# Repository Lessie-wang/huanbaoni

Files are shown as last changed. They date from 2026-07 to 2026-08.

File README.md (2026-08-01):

# 环抱你 · 知愈 Ring

> 一枚会「环抱你」的情绪陪伴戒指 —— 情绪实时感知、压力早期拦截、成长画像与温柔陪伴。
>
> Buildathon 2026 参赛项目。

戒指两端是一双抽象的手，共同托住可拆卸的六瓣「情绪核心」。它读你的心率与 HRV，识别压力的到来，在你还没意识到之前先用一次轻震「拦」住它；一天结束时，把你的情绪画成一幅画，让小知陪你复盘。

- **线上体验（GitHub Pages）**：https://lessie-wang.github.io/huanbaoni/
- **线上体验（Netlify）**：https://huanbaoni.netlify.app/
- 内置 demo 数据，扫码即用，无需连接真实硬件即可跑通全流程。

---

## 这是什么

「环抱你」= **一枚戒指硬件** + **一个 H5 App**。

- **戒指（输入端）**：MAX30102 采心率/HRV、MPU6050 采运动与「敲击」手势、GSR 采皮肤电，ESP32-S3 通过 BLE 上报，收到指令时用振动马达输出私密触觉。
- **H5（输出端）**：Web Bluetooth 直连戒指，实时显示压力状态；压力升高时分三档触觉干预（早期拦截 / 中期安抚 / 高压环抱）；当天情绪汇总成「心灵画像」，AI 管家「小知」陪你复盘、做量表自测和表达训练。

三档干预触觉的设计意图：**在压力形成早期就打断它**，而不是等崩溃后才安慰。

---

## 目录结构

| 目录 | 内容 |
|---|---|
| `webapp/` | 纯前端 H5 App（无框架、无构建，`index.html` 直接打开即跑）。5 个 Tab + 悬浮 AI 管家小知 |
| `firmware/` | ESP32-S3 Arduino 固件。`huanbaoni/` 是主固件，其余为各传感器 bringup 测试 sketch |
| `hardware/` | 演示外壳（OpenSCAD 源 + STL + 渲染图），容纳开发板与传感器托盘 |
| `cad/` | 戒指本体 3D 打印原型（Blender 源 + 多版本 STL + 预览图） |
| `docs/` | 接口契约、硬件规格、科学依据、分工清单 |
| `tools/` | 上线与现场保险工具（二维码生成、本地兜底服务） |
| `.github/workflows/` | GitHub Pages 自动部署 |

---

## H5 App（`webapp/`）

纯 HTML + CSS + vanilla JS，无框架、无构建步骤。底部 **5 个 Tab**（环抱居中凸起）+ 悬浮 AI 管家小知：

| 页面 | 类型 | 文件 | 作用 |
|---|---|---|---|
| 环抱（主页） | Tab | `pages/realtime.js` | 连戒指 → 实时 HR/HRV → 三色压力环；压力升高自动分档震动 |
| 心灵画像 | Tab | `pages/portrait.js` | 汇总当日情绪 → AI 生成一幅画 + 解读，诚实呈现而非美化负面情绪 |
| 心迹 | Tab | `pages/growth.js` | 画像画廊（色调演变）+ 情绪/压力趋势 + 等级/徽章/连续天数 |
| 探索 | Tab | `pages/tests.js` | HSPS-12 / PSS-10 等学术量表自测 + AI 解读 |
| 修习 | Tab | `pages/training.js` | 表达训练 + 感官写作 |
| 小知（AI 管家） | **悬浮窗** | `pages/chat.js` | 语音闭环对话；压力事件后主动发起复盘；**敲两下戒指**即可全局唤起并开录 |

共享层 `webapp/lib/`：`store.js`（localStorage）、`ble.js`（Web Bluetooth）、`mock.js`（假戒指数据）、`ai.js`（AI 调用）、`tts.js`（语音）、`tokens.css`（设计变量）等。

### 本地运行

直接用浏览器打开 `webapp/index.html` 即可（内置 mock 数据）。或起个静态服务：

```bash
cd webapp && python3 -m http.server 8080
# 打开 http://localhost:8080/
```

连接真实戒指需要支持 Web Bluetooth 的浏览器（Chrome / Edge），并通过 HTTPS 或 localhost 访问。

---

## 固件（`firmware/`）

- `huanbaoni/huanbaoni.ino` —— 主固件：MAX30102 算 HR/HRV、MPU6050 出运动量与双击手势、GSR 读皮肤电，全部通过 BLE Notify 上报；接收 `VIBRATE:*` 指令播放分档振动。
- 其余为分模块 bringup 测试：`i2c_scan/`（扫地址）、`hrtest/`、`gy521test/`、`gsrtest/`、`motortest/`、`mictest/`、`firstlight/`、`bringup_test/`。

BLE UUID、数据格式、下行指令等**接口契约见 [`docs/接口契约.md`](docs/接口契约.md)**（固件与 H5 必须字符串完全一致）。接线针脚与模块尺寸见 [`docs/硬件规格与外壳.md`](docs/硬件规格与外壳.md)。

---

## 部署与上线

**GitHub Pages**：push 到 `main` 后，`.github/workflows/pages.yml` 自动把 `webapp/` 发布为站点根。首次需在仓库 **Settings → Pages → Source = GitHub Actions** 开启一次。

**二维码与现场保险**（网络抽风时用本地热点兜底）见 [`tools/README.md`](tools/README.md)。

---

## 科学依据

压力检测的信号组合（心率 + HRV + 皮肤电 + 加速度）与学术界公认范式一致（WESAD 数据集），触觉干预亦有文献支撑。完整引用见 [`docs/科学依据.md`](docs/科学依据.md)。

---

## 技术栈

纯前端 H5（HTML/CSS/vanilla JS，零依赖零构建）· ESP32-S3 + Arduino · Web Bluetooth · OpenSCAD / Blender 建模。

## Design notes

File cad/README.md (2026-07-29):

# FeelingMosaic「环抱你」3D 打印原型 V1

## 设计结论

- 戒指定位为外观展示原型，不强行容纳 ESP32、MAX30102 开发模块和驱动板。
- 功能演示采用分布式原型：MAX30102 作为外置指夹采集，戒指或手部插件负责震动，ESP32 与驱动板放入底座。
- 戒指是开放式 C 环；两端为抽象双手，共同托住可拆卸六瓣情绪核心。
- 戒圈外有一条绕截面翻转一周的脊线，形成莫比乌斯视觉意象，同时不侵占主要佩戴空间。
- `FeelingMosaic` 字样在 Blender 精修阶段沿戒圈外侧雕刻；底座正面使用更大的品牌字样，保证 FDM 可读性。

## 现场设备约束

Buildathon OnePage 第六章列出的现场打印机型号为 Bambu Lab A1、P2S、X2D、H2D，提供 PLA：红、橙、黄、绿、蓝、黑、灰、白。文档没有列出透明耗材，并提醒硬件资源数量有限、对稳定性有要求时应自备材料。

因此：

- 默认使用白色 PLA 打印主体，灰色或黑色打印结构件。
- 莫兰迪粉棕、香槟金细节通过自带耗材、丙烯笔或喷漆实现。
- “透明底座”不是全透明 PLA，而是开放框架加 0.5-1 mm PET/亚克力透明片。
- 比赛前优先打印戒指和底座；现场打印只作为迭代或备用。

## 戒指参数

| 版本 | 内径 | 用途 |
|---|---:|---|
| S | 18.5 mm | 食指偏细 |
| M | 19.5 mm | 默认版本，优先打印 |
| L | 20.5 mm | 食指偏粗或需要宽松佩戴 |

- 戒圈总宽约 6 mm，最小主体厚度约 3.4 mm。
- 开口角约 60°；PLA 不应反复掰折，建议通过三种尺寸选配，而不是依赖弹性调节。
- 六瓣核心单独打印，可使用两枚 3×2 mm 磁铁或少量可移胶固定。
- 抽象手指直径约 1.1 mm，已按 0.4 mm 喷嘴的可打印下限加粗。
- 可选震动插件预留常见 10 mm 纽扣马达空间；驱动板仍放在底座。

## 底座架构

### 共用电子托盘

- 外形：140×95×12 mm。
- 内部用于放置 ESP32-S3、400 孔面包板、马达驱动板及杜邦线。
- 两条内部导轨用于扎带、双面胶或魔术贴固定。

### 封闭展示版

- 使用 `opaque_emotion_island_lid` 覆盖电子托盘。
- 顶部六瓣浮雕和戒指展示架构成“情绪岛屿”。
- 后侧预留 USB 走线区域；最终精修时再按实物线头开孔。

### 开放透明版

- 使用 `open_clear_panel_frame` 安装在电子托盘上。
- 四周框架之间安装 PET、亚克力或透明包装片，展示内部原型结构。
- 不使用现场未列明的透明 PLA，避免成品浑浊且打印失败。

## 手上震动演示

优先方案：

1. 购买 10 mm 左右、已带引线的纽扣震动马达。
2. 将马达放入 `optional_10mm_coin_motor_insert`。
3. 插件用医用双面胶、透明胶贴在食指侧面或戒指下方。
4. 细线沿手背进入袖口，再连接底座中的驱动板。

无小马达时：将现有带驱动板的震动模块固定在手腕内侧，用腕带遮住，仍能保证震动真实发生在手上。

## 推荐切片参数

- 材料：PLA。
- 喷嘴：按现场机器默认设置；模型按常见 0.4 mm 喷嘴设计。
- 层高：戒指 0.16-0.20 mm；底座 0.24-0.28 mm。
- 墙数：戒指 3-4；底座 2-3。
- 填充：戒指 25-35%；底座 10-15%。
- 支撑：戒指建议树状支撑，仅从热床生成；底座主体尽量不加支撑。
- 首次打印顺序：M 戒指 → 六瓣核心 → 震动插件 → 电子托盘 → 选一个底座上盖。

## 文件

- `cad/output/feelingmosaic_ring_18.5mm.stl`
- `cad/output/feelingmosaic_ring_19.5mm.stl`
- `cad/output/feelingmosaic_ring_20.5mm.stl`
- `cad/output/six_petal_emotion_core.stl`
- `cad/output/electronics_tray_140x95.stl`
- `cad/output/opaque_emotion_island_lid.stl`
- `cad/output/open_clear_panel_frame.stl`
- `cad/output/optional_10mm_coin_motor_insert.stl`

每个 STL 同时提供 OBJ，方便导入 Blender 后做布尔合并、雕字、材质渲染和局部造型调整。

## Blender 精修清单

1. 对戒指主体执行 Voxel Remesh 或 Boolean Union，消除重叠壳体。
2. 沿戒圈外侧雕刻 `FeelingMosaic`，字高不小于 2.5 mm、笔画不小于 0.8 mm、深度 0.5-0.7 mm。
3. 在六瓣核心和双手托座增加 3.2×2.2 mm 磁铁孔。
4. 根据实物 USB 插头、开关和线材尺寸修改底座开孔。
5. 使用 Bambu Studio 的模型修复功能检查非流形边并预览逐层切片。

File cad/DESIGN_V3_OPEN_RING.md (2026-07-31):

# FeelingMosaic「环抱你」开口戒指 V3

## 当前推荐方案

V3 保留 V2 的高级几何与莫比乌斯语言，但完全移除中央宝石：

- 戒指是清晰的开放式 C 环。
- 八面切角截面沿戒圈扭转 180°。
- 两端抽象为相向伸出的几何双手。
- 中央最窄开口约 5 mm，没有宝石、横梁或隐藏连接件。
- 三根渐细指片与下方拇指共同框出负空间，表达“想要拥抱但不过度侵入”。

## 推荐外观

- 首选：枪灰或钛灰哑光主体。
- 备选：哑光银主体，切面边缘轻微抛光。
- 不建议粉色、圆润高光或彩色花朵装饰。
- `FeelingMosaic` 后续刻在戒圈较宽的外侧切面，或只刻在戒指内壁。

## 输出文件

路径：`cad/output/open_v3/`

- `feelingmosaic_open_embrace_ring_18.5mm.stl`
- `feelingmosaic_open_embrace_ring_19.5mm.stl`（默认）
- `feelingmosaic_open_embrace_ring_20.5mm.stl`

每个 STL 同时提供 OBJ。

## 尺寸与打印

- 默认内径：19.5 mm。
- 默认外形约：32.4×33.7×6.0 mm。
- PLA 层高：0.12-0.16 mm。
- 墙数：4；填充：30-40%。
- 建议以开口向上、整体倾斜 30-45° 的方式打印，并使用树状支撑。
- 当前文件由多个封闭实体组成；导入 Bambu Studio 后使用“修复模型/合并重叠体”，或在 Blender 中执行 Voxel Remesh 后再切片。

## 预览

- `cad/previews/open_ring_v3_top.png`
- `cad/previews/open_ring_v3_isometric.png`
- `cad/previews/open_ring_v3_front.png`

底座设计暂缓，后续围绕最终戒指比例重新设计。

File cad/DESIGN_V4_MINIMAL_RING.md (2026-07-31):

# FeelingMosaic 极简开口戒指 V4

## 最终方向

- 删除双手、宝石、镶爪及所有向上翘起的装饰。
- 保留一个干净的开放式圆形 C 环。
- 戒圈采用八面切角截面，视觉高级但不尖锐。
- 两端在约 7 个截面内逐渐收窄至 72%，形成低轮廓钝头。
- 戒圈保留轻微的莫比乌斯半圈扭转，但没有任何结构高于主体轮廓。

## 默认尺寸

- 内径：19.5 mm。
- 外形约：31.4×29.2×5.5 mm。
- 开口角：38°。
- 适合先用灰色或黑色 PLA 打样。

如果实戴偏紧或偏松，同时提供 18.5 mm 和 20.5 mm 两个版本。PLA 不建议通过反复掰动调整尺寸。

## 输出文件

路径：`cad/output/minimal_v4/`

- `feelingmosaic_minimal_open_ring_18.5mm.stl`
- `feelingmosaic_minimal_open_ring_19.5mm.stl`（默认）
- `feelingmosaic_minimal_open_ring_20.5mm.stl`

每个 STL 同时提供 OBJ。

## 打印建议

- 层高：0.12-0.16 mm。
- 墙数：4。
- 填充：30-40%。
- 开口向上，戒圈倾斜 30-45°，使用树状支撑。
- 打印后用 600-1000 目砂纸轻磨端部和外侧切面。
- 表面可喷钛灰、枪灰或哑光银，再覆盖哑光清漆。

## 预览

- `cad/previews/minimal_ring_v4_top.png`
- `cad/previews/minimal_ring_v4_isometric.png`
- `cad/previews/minimal_ring_v4_front.png`

底座暂不继续设计，优先确认戒指实戴比例。

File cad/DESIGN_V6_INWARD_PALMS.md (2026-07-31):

# FeelingMosaic 内向掌心开口戒指 V6

## 当前造型

- 保留开放式圆形戒圈和低调的莫比乌斯扭转。
- 两只手与戒圈端部保持同一高度，不向上翘起。
- 掌片整体向戒指内圆收拢，掌心朝向圆心。
- 每只手的三根几何手指从掌片内缘伸入圆内，形成托住、包覆圆心的拥抱姿态。
- 两手不接触，中央仍保留明确开口。

## 安全与佩戴

- 手部最大半高约 1.7 mm，低于戒圈约 2.75 mm 的最大半高。
- 两手最小打印间隙约 3.1 mm，避免 FDM 拉丝后粘连成一体。
- 手指端部为平直钝面，没有朝上尖角。
- 默认版本整体约 31.3×29.3×5.5 mm。
- 模型为概念展示戒指，正式佩戴前仍建议打磨所有切面和端部。

## 输出文件

路径：`cad/output/inward_palms_v6/`

- `feelingmosaic_inward_palms_ring_18.5mm.stl`
- `feelingmosaic_inward_palms_ring_19.5mm.stl`（默认）
- `feelingmosaic_inward_palms_ring_20.5mm.stl`

每个 STL 同时提供 OBJ。

## 预览

- `cad/previews/inward_palms_ring_v6_top.png`
- `cad/previews/inward_palms_ring_v6_isometric.png`
- `cad/previews/inward_palms_ring_v6_front.png`

V6 取代 V5，修正了掌心向外的问题。

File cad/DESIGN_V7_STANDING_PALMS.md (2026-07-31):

# FeelingMosaic 立掌环抱开口戒指 V7

## 这版修正

- V6 的手虽然伸向内圆，但掌片仍然平躺在戒指平面中。
- V7 以左右戒圈端点的局部切线为旋转轴，将整只手旋转 90°。
- 掌心、三根几何手指和拇指作为完整整体一起立起，没有重新拼成独立装饰片。
- 两只手原本朝上的掌面旋转后都朝向戒指内圆，形成相对收拢的环抱姿态。

## 几何与佩戴

- 默认内径为 19.5 mm，另提供 18.5 mm 和 20.5 mm。
- 默认模型外形约为 31.3 × 31.0 × 6.0 mm。
- 默认模型两手最小顶点间隙约 2.87 mm，适合保留清晰开口。
- 所有尺寸版本的导出网格均无退化三角形、边界边或非流形边。
- 手掌立起后会比平掌版本更容易接触相邻手指，试戴前需要打磨掌缘和指尖。

## 输出文件

路径：`cad/output/standing_palms_v7/`

- `feelingmosaic_standing_palms_ring_18.5mm.stl`
- `feelingmosaic_standing_palms_ring_19.5mm.stl`（默认）
- `feelingmosaic_standing_palms_ring_20.5mm.stl`

每个 STL 同时提供 OBJ。

## 预览

- `cad/previews/standing_palms_ring_v7_gap.png`：从内圆看两只相对掌心。
- `cad/previews/standing_palms_ring_v7_isometric.png`：整体立体效果。
- `cad/previews/standing_palms_ring_v7_top.png`：确认掌片已不再平躺。
- `cad/previews/standing_palms_ring_v7_front.png`：确认手部高度与戒圈关系。

## 打印建议

- 现场展示优先使用 PLA 或 PLA Silk，层高 0.12–0.16 mm，4 道墙。
- 建议让戒圈侧面贴平台或倾斜 30–45°，避免立掌悬空面直接横向打印。
- 开启树状支撑，仅从热床生成，并重点检查掌心背面和指尖下方。
- 切片时合并重叠体；若切片器未自动合并，先在 Blender 中做体素重构或布尔并集。

V7 取代 V6 作为当前立掌方向版本。

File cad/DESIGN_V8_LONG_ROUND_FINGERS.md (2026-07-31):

# FeelingMosaic 加长圆指立掌戒指 V8

- 两只手保持 V7 的立掌、掌心相对姿态。
- 三根手指沿拥抱方向加长，并改为圆柱中段与半球圆头。
- 手指打印直径约 1.28–1.44 mm，适合 0.4 mm 喷嘴的现场 FDM 展示打印。
- 默认 19.5 mm 内径版本两手最小间隙约 1.63 mm。
- 默认外形约 31.3 × 31.0 × 6.8 mm。
- 三种尺寸网格校验均无退化三角形、边界边或非流形边。

默认文件：`cad/output/long_round_fingers_v8/feelingmosaic_long_round_fingers_ring_19.5mm.stl`

快速打印建议：0.4 mm 喷嘴、0.12–0.16 mm 层高、4 道墙、20–35% 填充、树状支撑仅接触热床。建议将戒指侧放或倾斜 35–45°，不要让两只立掌完全悬空横打。

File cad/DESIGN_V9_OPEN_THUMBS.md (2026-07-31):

# FeelingMosaic 张开拇指立掌戒指 V9

- 保留 V8 的立掌、加长圆指和掌心相对姿态。
- 两侧拇指从手指排中分离，向掌心内下方张开约 18°。
- 拇指比其他手指更短、更粗，根部嵌入掌心，末端为圆头。
- 默认内径 19.5 mm，外形约 31.3 × 31.1 × 7.6 mm。
- 默认两手最小间隙约 1.63 mm。
- 网格校验结果为 0 个退化三角形、0 条边界边、0 条非流形边。

立即打印文件：`cad/output/open_thumbs_v9/feelingmosaic_open_thumbs_ring_19.5mm.stl`

建议使用 0.4 mm 喷嘴、0.12–0.16 mm 层高、4 道墙、25–35% 填充。戒指侧放或倾斜 35–45°，树状支撑仅接触热床，重点支撑掌心和张开的拇指下方。

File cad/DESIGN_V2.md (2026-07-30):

# FeelingMosaic「环抱你」高级几何版 V2

## 方向调整

V1 的圆管、花瓣和圆润手掌偏可爱，不再作为主方案。V2 改为珠宝、建筑与工业设计语言：

- 戒圈使用八面切角截面，而不是圆管。
- 截面沿 C 环完成 180° 扭转，莫比乌斯变化直接体现在实体轮廓中。
- 两端的“手”不再写实或圆润，而是抽象成对称的几何掌片、三根镶爪和一根拇指支撑。
- 中央核心改为独立的八面切割宝石，可后续增加 3×2 mm 磁铁孔。
- 底座改为倒角矩形、折面平台和斜撑结构，去除花瓣和水波纹。

## 推荐视觉

- 戒圈：枪灰、钛灰或哑光黑。
- 几何手部：同色金属，或局部香槟银。
- 核心：烟绿色、深海蓝或透明树脂件。
- 封闭底座：浅灰石材感上盖 + 枪灰展架。
- 开放底座：黑色框架 + 0.5-1 mm 透明 PET/亚克力片。

比赛现场只有基础色 PLA 时，优先选择灰色或黑色。打印后使用 600-1000 目砂纸打磨，再喷金属灰底漆和哑光清漆，会比直接使用亮色 PLA 更高级。

## 戒指尺寸

| 文件 | 内径 | 建议 |
|---|---:|---|
| `feelingmosaic_luxury_ring_18.5mm.stl` | 18.5 mm | 食指偏细 |
| `feelingmosaic_luxury_ring_19.5mm.stl` | 19.5 mm | 默认优先打印 |
| `feelingmosaic_luxury_ring_20.5mm.stl` | 20.5 mm | 宽松或食指偏粗 |

默认 19.5 mm 版外形约 32.4×33.7×6.0 mm。主体最薄截面仍超过常见 0.4 mm 喷嘴的安全打印下限。

## 品牌文字

戒指本体较小，FDM 直接打印完整 `FeelingMosaic` 容易糊字。V2 建议：

1. 戒圈只做激光雕刻、转印或油漆笔书写的 `FeelingMosaic`；
2. 底座正面的 64×11 mm 品牌条打印完整名称；
3. 若后续使用树脂打印，再把 0.4-0.6 mm 深的完整文字刻入戒圈外侧。

## V2 输出文件

路径：`cad/output/luxury_v2/`

- 三种尺寸高级戒指 STL/OBJ。
- `faceted_mosaic_core.stl`：切割宝石核心。
- `luxury_electronics_tray_150x100.stl`：150×100 mm 电子托盘。
- `luxury_closed_architectural_lid.stl`：封闭建筑感上盖。
- `luxury_open_display_frame.stl`：透明片开放框架。

## 打印建议

- 戒指层高：0.12-0.16 mm。
- 戒指墙数：4；填充 30-40%。
- 戒指摆放：开口向上倾斜约 30-45°，使用树状支撑。
- 宝石核心：平放打印；如果使用磁铁，先打印无孔版确认比例，再按磁铁实测尺寸开孔。
- 底座层高：0.20-0.28 mm；墙数 3；填充 10-15%。
- 开放框架建议黑色 PLA；封闭上盖建议灰色 PLA。

## 预览

- `cad/previews/luxury_ring_v2_isometric.png`
- `cad/previews/luxury_ring_v2_top.png`
- `cad/previews/luxury_base_v2_variants.png`

V2 为当前推荐方向，V1 文件仅保留作方案对比。

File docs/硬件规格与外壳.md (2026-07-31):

# 硬件规格与外壳设计 · 「环抱你·小白」

> 本文件汇总所有硬件模块的实测尺寸、接线针脚与外壳设计方案，供 3D 建模和演示搭建复用。
> 图片存于 `docs/hardware/`（已从临时来源复制进仓库，长期有效）。

---

## 一、模块尺寸总表

| 模块 | 作用 | 尺寸 (mm) | 关键点 | 图 |
|---|---|---|---|---|
| ESP32-S3 主控 | 主控 + BLE | PCB 27.9 × 57.2（含 USB 端到端 63.3） | 双 Type-C 在短边并排；排针行间距 25.4；PCB 厚 1.6 | `hardware/esp32-s3.png` |
| MAX30102 | 心率 / HRV / 血氧 | 15.5 × 20 | 感光窗在板中央，需**朝上贴指腹** | `hardware/max30102.jpg` |
| MPU6050 (GY-521) | 六轴运动 + 敲击手势 | 21 × 16 | 8 针：INT/ADO/XCL/XDA/SDA/SCL/GND/VCC | `hardware/mpu6050.jpg` |
| 振动马达模块 | 私密震动输出 | 板 21 × 30；马达 ⌀10 × 厚 2.7（扁平） | 固定孔 ⌀3，孔距 15；5V，MOS 高电平触发；针 IN/VCC/GND | `hardware/motor.jpg` |
| INMP441 麦克风 | 环境音（P1，可选） | 14 × 14 圆板 | 装盒内，I2S | `hardware/inmp441.jpg` |
| GSR 皮肤电 | 情绪唤醒 | 34 × 25，重 4g | **3.5mm 音频座**接指套电极；针 GND/VCC/OUT；3.3–5V | `hardware/gsr.jpg` |
| 半长面包板 | 走线底板 | 56 × 83 × 8.5（由原方案减半） | ABS，0.8mm 跳线 | `hardware/breadboard.jpg` |

**待补测量**（无卡尺可先跳过，试打后微调）：
- ESP32 两个 Type-C 口的**中心间距**、**口下沿距 PCB 底面高度**、口是否凸出板边。
- 各模块焊排针后的**总高**。

---

## 二、接线针脚对照（与 `docs/接口契约.md` / 固件一致）

| 模块针脚 | 接到 ESP32 | 说明 |
|---|---|---|
| MAX30102 SDA / SCL | GPIO8 / GPIO9 | I2C（与 MPU 共用总线，地址 0x57） |
| MAX30102 VIN / GND | 3V3 / GND | |
| MPU6050 SDA / SCL | GPIO8 / GPIO9 | I2C 并联（地址 0x68，AD0→GND） |
| MPU6050 VCC / GND | 3V3 / GND | |
| 振动马达 IN | GPIO5 | PWM，高电平触发 |
| 振动马达 VCC / GND | 3V3 / GND | |
| GSR OUT | GPIO10 | ADC1（必须 GPIO1~10，避开 ADC2 与 BLE 冲突） |
| GSR VCC / GND | 3V3 / GND | |
| GSR 3.5mm 座 | — | 外接两指电极 |
| INMP441 (I2S) | 参见 mictest 接线 | P1 可选，未接进主固件 |

> ⚠️ 3V3 针脚只有两个 → 面包板电源轨分电。**注意：面包板电源轨中间有断缝，左右两半不通，务必跨接或同侧取电**（曾因此调试数小时）。

---

## 三、「环抱你·小白」立体角色外壳

> 外观不是盒子贴角色，而是一个无脸、无耳的抽象拥抱精灵。矩形电子仓只存在于梨形肚子的内部，任何外部视角都保持连续椭圆曲面。

### 空间与轮廓

- **内部净空**：`62 × 32 × 90mm`，半长面包板 `56 × 83 × 8.5mm` 竖装；ESP32、GSR、马达驱动和走线仍使用原规划深度。
- **主体外形**：约 `110 × 82 × 153mm`（不含向前伸出的抱臂）；由一条稠密的梨形曲线旋转成型，再做前后椭圆压缩，整个肚子是一张连续曲面。
- **整体握持深度**：含抱臂约 `117mm`；双臂前移后，肚子与前臂之间留 `hand_clearance=22mm` 净空。
- **识别方式**：无五官、无耳朵、无戒指或 Ring 字样；只用小头、梨形身体和“抱住人的手”的动作表达「环抱你」。
- **壳体结构**：身体沿左右侧轮廓分为前/后两半，接缝位于 `y=0`；后壳四枚 `⌀5.8mm` 球头扣入前壳带释压槽的卡座，保留约 0.35mm 配合量，可反复开壳调试。

### 握持交互

1. 用户从正面把手掌插入小白肚子与双臂之间。
2. 掌心自然压住正面的 MAX30102 H 型托盘，手指可以环握梨形肚子。
3. 小白的粗短 C 形手臂包在手掌两侧，掌球和大拇指位于内上侧，不压传感器。
4. `hand_clearance` 是单一可调参数；试握后只需改这个值即可前后移动整段抱臂。

### 功能接口布局（尺寸不变）

- **正面**：仅 MAX30102 H 型托盘，板槽 `15.5 × 20mm`、总开口宽 `17mm`、中桥 `4.5mm`、双侧贯穿槽长 `20mm`。
- **背面上方**：MPU6050 L 型托盘，板位 `16 × 21mm`、排针槽 `5 × 22mm`，方便直接敲击。
- **背面中部**：GSR 和马达两个 `⌀9mm` 圆孔，中心距 `14mm`。
- **真正底部（两脚之间）**：双 Type-C 独立孔，每个 `11 × 6mm`，横向中心距仍为待实测的 `13mm`。ESP32 在下腹中央竖装：PCB 宽 `27.9mm` 由左右导轨夹持，`57.2mm` 长轴沿身体高度，Type-C 短边垂直朝下。拿起小白即可插线，站立时两脚把接口架空；这避免了背向安装所需的 `63.3mm` 前后空间，也不占面包板后层。

### 工程校验

- `wall_check` 会将主电子仓和 ESP32 下腹板槽向外扩 2.4mm 后与梨形内壳求差（忽略底部 Type-C 开口所在的 `z<5mm`）；当前结果为空，表示所需净空完整装得下。
- 手臂通过隐藏的 `⌀7.4mm` 肩榫插入前壳，孔侧留 0.35mm 配合量，实际握持受力不只依赖胶面；手臂本体采用连续曲线扫掠网格，圆肩—圆肘—前臂之间没有分段锥面。
- 前壳、后壳、左右手臂均已通过 OpenSCAD CGAL 封闭实体检查。
- ⚠️ 试打前仍必须实测 `usb_center_spacing`，这是目前唯一沿用估值的关键接口参数。

### 文件与导出

- 参数化源文件：`hardware/enclosure.scad`
- 单件：`hardware/body_front.stl`、`hardware/body_back.stl`、`hardware/arms.stl`
- 一次排版：`hardware/print_all.stl`（前后壳接缝面朝下，双臂侧躺；适配 256 × 256mm 打印板）
- 预览：`hardware/assembled.png`、`hardware/assembled_front.png`、`hardware/assembled_back.png`、`hardware/assembled_side.png`
- `show`：`assembled` / `body_front` / `body_back` / `arm` / `arm_l` / `arms` / `grip_check` / `cavity_check` / `wall_check` / `print`

```bash
openscad -o hardware/body_front.stl -D 'show="body_front"' hardware/enclosure.scad
openscad -o hardware/body_back.stl  -D 'show="body_back"'  hardware/enclosure.scad
openscad -o hardware/arms.stl       -D 'show="arms"'       hardware/enclosure.scad
openscad -o hardware/print_all.stl  -D 'show="print"'      hardware/enclosure.scad
```

建议全体使用暖白 PLA；手臂与身体同色，靠真实体块和阴影表达拥抱，不再使用肤色贴件或表面角色图案。

---

## 四、打印时间优化

- 主体由“实心体块再挖矩形槽”改为约 `2.8–4.0mm` 的连续有机薄壳，外观、内部净空和所有接口坐标不变。
- 面包板和 ESP32 不再依赖大块实心托盘，改用两侧导轨、底托/顶挡和与壳体相连的短加强筋。
- 四枚球头卡扣各用一条窄径向筋连回后壳，位于 `62mm` 电子仓宽度之外，不会挤占元器件空间。
- 手臂仍为同一条连续扫掠曲面，只将网格采样从 `40×40` 降为 `28×28`；圆肩、圆肘和掌球的实际尺寸不变。
- STL 体积校验：前后壳合计由约 `528.7cm³` 降为 `187.6cm³`，减少约 **64.5%**。这是用料/打印时间的几何代理值；最终分钟数仍取决于层高、壁数、填充和支撑策略。

推荐切片起点：`0.24mm` 层高、3 道壁、15% 局部填充；前后壳用平整接缝面朝下，手臂侧躺并仅对悬空局部生成支撑。

---

## 五、模块图片索引

- ESP32-S3 主控（含 mil 尺寸）：`hardware/esp32-s3.png`
- MAX30102 心率血氧：`hardware/max30102.jpg`
- MPU6050 GY-521：`hardware/mpu6050.jpg`
- 振动马达模块：`hardware/motor.jpg`
- INMP441 麦克风：`hardware/inmp441.jpg`
- GSR 皮肤电传感器：`hardware/gsr.jpg`
- 面包板：`hardware/breadboard.jpg`

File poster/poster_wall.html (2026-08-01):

知愈 · Ring 真系列

软 硬 兼 得 BUILDATHON 2026 · NEXT WORLD

「环抱你」

会环抱你的情绪伙伴

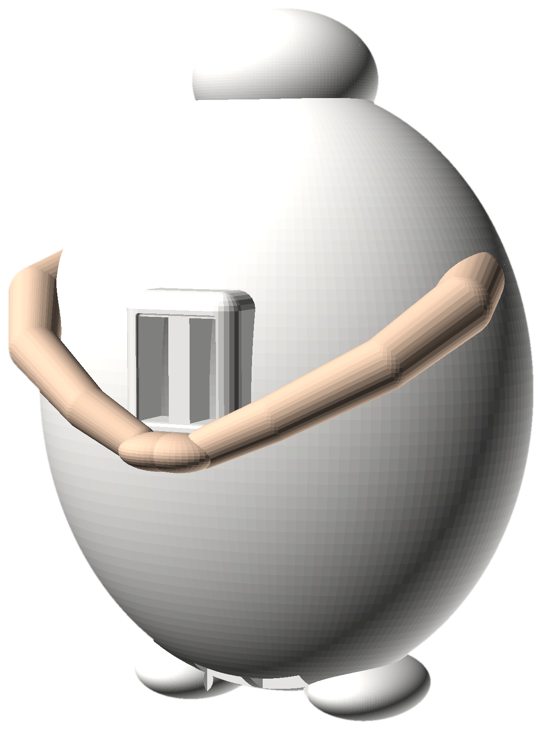
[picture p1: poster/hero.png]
环抱你


舒展 波动 紧绷

先环抱自己，再环抱你

白色身体 · 鎏光香槟手臂 · 未来集成于指间

你的身体，比你先知道 ——
它，是身体递给意识的那张纸条。

HARDWARE无感采集层· 戴上即感知，记录成本归零

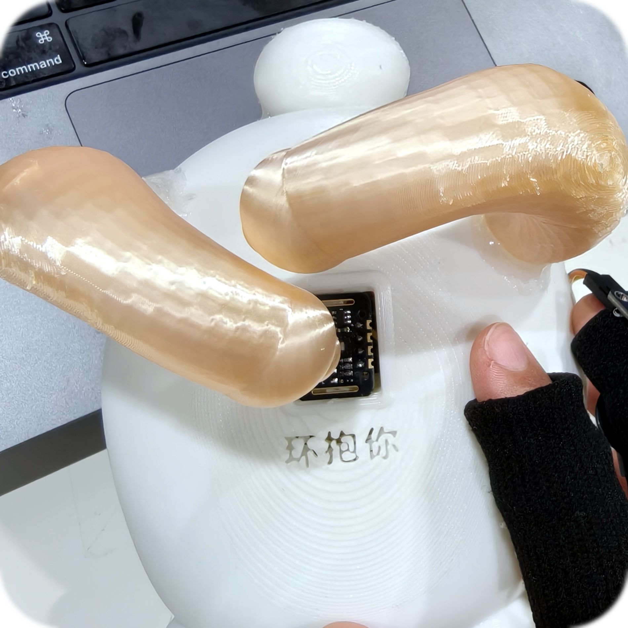
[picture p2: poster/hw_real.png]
真机
真机实拍 

小白 · ESP32-S3 + 五传感器 · 现场手作

PRE-CONSCIOUS

身体比你先知道

HRV 在你意识到之前先塌陷
抓住那 10–20 秒预警窗

心率 · HRVMAX30102

光学采集，衡量绷紧还是放松

皮肤电 GSR唤醒

情绪唤醒，先于意识升高

运动 + 敲击MPU6050

区分紧张与手部活动 · 敲两下唤醒

私密震动三档

只有你知道的那一下：拦截·锚定·撤退

SOFTWARE情绪炼金层· 把冷数据，炼成一个心灵世界

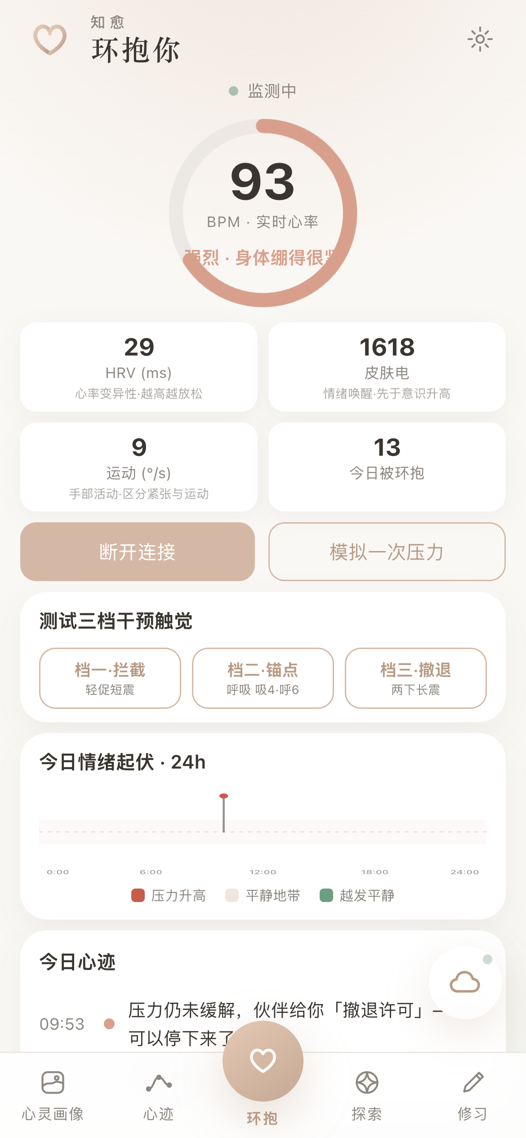
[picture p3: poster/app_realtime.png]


实时环抱三色压力环 · 私密震动

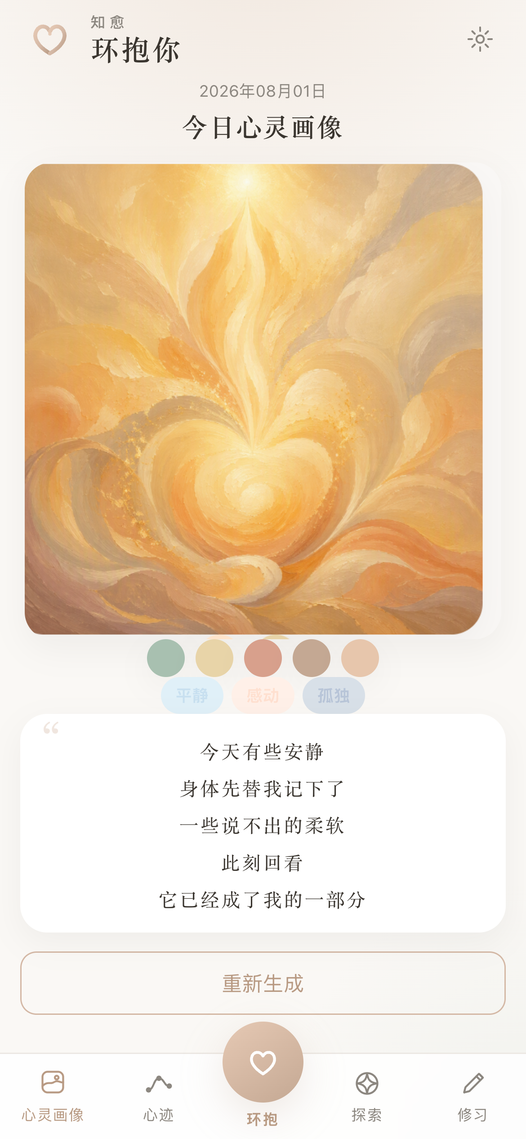
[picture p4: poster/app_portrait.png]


今日心灵画像AI 把情绪炼成画

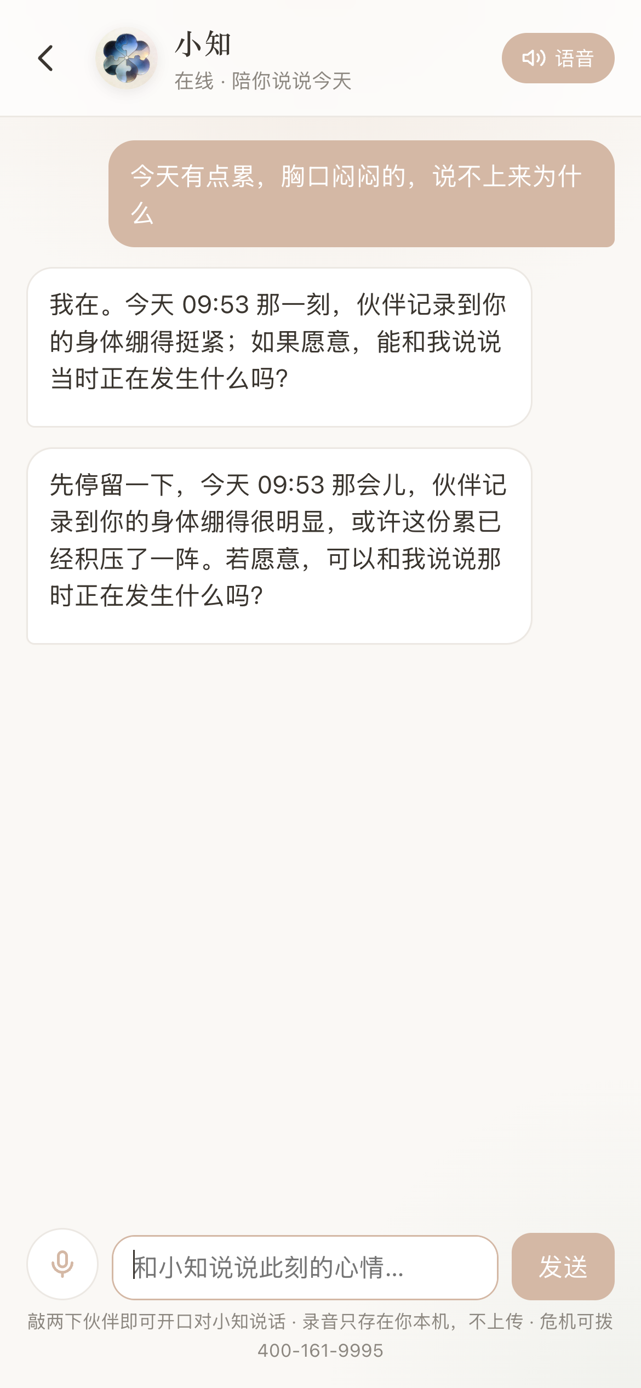
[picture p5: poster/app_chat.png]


小知复盘敲两下伙伴，陪你说说

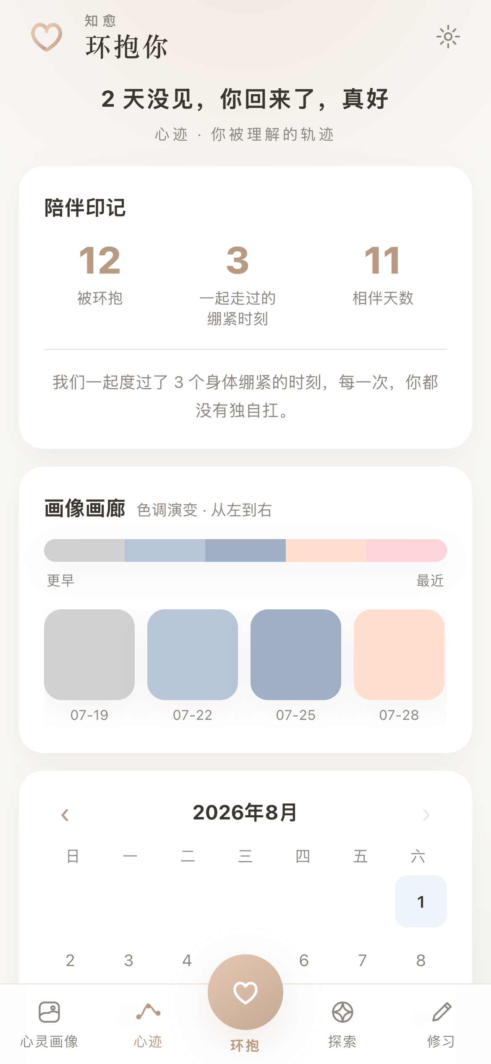
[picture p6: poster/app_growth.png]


心迹画廊色调由灰转暖

NEXT WORLD我们想象的下一个世界

不是一个更快、更强、逼人更完美的世界，
而是一个允许脆弱、更温柔、更能理解自己、也理解彼此的世界。

用「环抱你」环抱你

现场循环播放 · 60s Demo

HR · HRV · GSR · MOTION
PRIVATE HAPTIC · ESP32-S3

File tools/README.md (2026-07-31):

# tools —— 上线与现场保险工具

## 线上（GitHub Pages）
代码 push 到 `main` 后，`.github/workflows/pages.yml` 自动把 `webapp/` 发布为站点根：

    https://lessie-wang.github.io/huanbaoni/

首次需在仓库 **Settings → Pages → Build and deployment → Source = GitHub Actions** 开启一次。

## 生成二维码
    python3 tools/make_qr.py "https://lessie-wang.github.io/huanbaoni/" tools/qr-online.png

优先用本地库（segno / qrcode），没有则自动走在线 API 兜底（需联网）。
建议装库更稳：`pip3 install segno`（或 `pipx`）。

## 现场保险（网络抽风时）
自己手机开热点、电脑连该热点，然后：

    bash tools/serve-local.sh          # 默认 8080 端口

它会打印局域网地址（如 http://192.168.x.x:8080/）。给这个地址生成二维码：

    python3 tools/make_qr.py "http://192.168.x.x:8080/" tools/qr-local.png

观众手机连同一热点即可扫码打开，全程不依赖公网。

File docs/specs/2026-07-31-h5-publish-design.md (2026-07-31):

# 设计：H5 上线（扫码可访问 + 零 API 配置）

> 日期：2026-07-31 · 目标：让「环抱你·小白」webapp 从本地跑变成手机扫码即用的公开 H5，用于 demo day 现场与后续留存。

## 背景与问题

- `webapp/` 是标准 hash 单页应用：所有页面（portrait / growth / realtime / tests / training / chat）在 `index.html` 一次性加载，靠 `location.hash` 切换，`route()` 统一渲染。
- 用户反馈「跳转后之前页面不加载/不显示」。经排查：**代码本身是连通的**，白屏根因是本地用 `file://` 直接打开导致 hash 路由 / 相对路径行为异常。上线到 http(s) 静态托管后预期自动消失。
- 用户希望：① 手机扫码就能打开的公开链接 + 二维码；② 零 API 配置，默认用主办方提供的 hackathon key，不让每个人自己填。

## 已验证的技术前提（实测）

- MaaS endpoint：`https://maas.devops.rednote.life/hackson`（`ai.js` 的 `_base()` 会自动补 `/v1`）。
- 文本模型 `gpt-5.6-sol`：`POST /v1/chat/completions` 返回 200，正常出文。
- 图片模型 `gpt-image-2`：`POST /v1/images/generations` 返回 200，`b64_json` 正常。
- **CORS 已开**：响应头回显任意 `Origin`，浏览器直连不被拦 → 前端写死 key 可直接跑通。

## 决策

| 维度 | 决定 | 理由 |
|---|---|---|
| API key | **写死在前端默认配置** | 用户接受；hackathon key 临时限额，活动后可回收。CORS 已开，前端直连可行。 |
| 戒指数据 | **保持 mock=true** | 现场观众无真戒指；关掉会导致环抱/心迹页无数据白屏。mock 只影响戒指，不影响真 AI。 |
| 上线平台 | **GitHub Pages** | 已有仓库 `Lessie-wang/huanbaoni`；国内手机网络下比 Vercel/Netlify 更常打得开（用户已验证 Vercel 打不开，Netlify 同为海外 CDN 不会更好）；push 即更新。 |
| 链接形式 | **Actions 发布 webapp/ 为站点根** | 干净链接 `https://lessie-wang.github.io/huanbaoni/`。 |
| 现场保险 | **本地起服务 + 局域网二维码脚本** | 网络抽风时用自己手机热点也能扫码演示。 |

## 改动清单

1. **`webapp/lib/store.js`** — `getSettings()` 默认值写死：
   - `apiBaseUrl = 'https://maas.devops.rednote.life/hackson'`
   - `apiKey = '<hackathon key>'`
   - `useMock = true`（戒指仍用模拟；AI 走真 key）
   - 兼容旧数据：若用户 localStorage 里已存空的 apiBaseUrl/apiKey，读取时用默认值兜底（避免老缓存把默认值覆盖成空）。
2. **`webapp/index.html`** — 设置弹窗文案标注「（可选覆盖，默认已配置好）」；不改交互。
3. **`.github/workflows/pages.yml`**（新增）— 用官方 `upload-pages-artifact` + `deploy-pages`，把 `huanbaoni/webapp/` 作为发布目录。
   - 注意：仓库根即 `huanbaoni/`，workflow 路径与 artifact path 以此为准。
4. **现场保险**（新增，放 `webapp/` 或 `tools/`）：
   - `serve-local.sh` — `python3 -m http.server` 起在 `webapp/`，打印局域网访问地址。
   - 生成两个二维码 PNG：线上链接 + 局域网链接。
5. **上线后验证**：逐页点击（portrait/growth/realtime/tests/training/chat），确认无白屏、小知能真实回话、画像能真实生成。发现个别页 bug 再单独修（验证驱动，不预设）。

## 非目标（YAGNI）

- 不做后端代理 / 云函数（用户选择写死前端）。
- 不做账号系统、数据云同步（仍用 localStorage）。
- 不重构页面路由（现有 hash 路由上线后即连通）。
- 不改 UI 视觉、不改各页业务逻辑（除非上线验证发现真 bug）。

## 风险

- **key 明文暴露**：任何访客可从源码读取。缓解：活动后回收 key / 设额度上限。已获用户知悉同意。
- **GitHub Pages 国内访问波动**：用本地局域网二维码作为现场 fallback。
- **老 localStorage 缓存**：曾在旧版填过空配置的设备，需默认值兜底逻辑覆盖；必要时设置弹窗加「恢复默认」。

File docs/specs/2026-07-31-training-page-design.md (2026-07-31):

# 「修习」页设计（环抱你 H5 · Agent F）

> 2026-07-31。落地 index.html 第 6 个 tab `training`（label「修习」），目前为占位。
> 对应 [分工清单.md](../分工清单.md) Agent F：`pages/training.js`，「表达训练 + 感官写作，搬知愈 subpages/training 内容与流程」。

## 目标

在 `huanbaoni/webapp` 里实现「修习」页，把知愈小程序两个成熟训练玩法搬成 vanilla-JS：
1. **模拟对话训练** — 情景对话，AI 同时演 NPC 与「小知教练」，逐轮点评打分，几轮后结算。
2. **感官写作** — 选情绪场景 → 逐个感官（视/听/触/嗅/味）引导写作 + 词语卡片 → 拼成成品段落 → 存档。

范围：**核心闭环**（不搬知愈的游戏化关卡地图/徽章/经验系统，符合分工表 P2 演示级定位）。

## 约束（项目"宪法"，不可破）

- 纯 HTML+CSS+vanilla JS，无框架、无构建，localhost 直接跑。
- 注册为 `window.Pages.training = { render(el) }`（同 chat.js/portrait.js）。
- 数据只经 `Store`；AI 只调 `AI.chat`；颜色只用 `tokens.css` 变量。
- **只新增/编辑 `pages/training.js`**，不动 `lib/`、不动其他页面、不改 index.html（它已引用本文件）。
- 无 API Key 时用本地 mock 兜底，保证 demo 全程可跑（同 chat.js 模式）。

## 文件改动

- **新增**：`huanbaoni/webapp/pages/training.js`（样式内联，同 chat.js，避免改 index.html 多引 css）。
- 其余文件：**零改动**。

## 页面结构（单文件状态机，学 chat.js）

```
render(el)
 ├─ view: 'home'      两张大卡「模拟对话」「感官写作」＋「修习记录」入口
 ├─ view: 'dialogue'  模拟对话流程
 ├─ view: 'writing'   感官写作流程
 └─ view: 'records'   历史存档列表 + 详情
```

内部用一个 `state` 对象 + `paint()` 重渲染当前 view，事件用委托绑定。

### A. 模拟对话训练

- **预置 4 场景**（搬知愈 pages/training.js dialogueScenarios）：日常沟通 / 表达拒绝 / 处理冲突 / 安慰他人；＋自定义场景输入。
- **流程**：选场景 → intro（背景+对方开场白）→ 逐轮对话 → 4–6 轮后结算。
- **每轮**：用户输入后 `AI.chat` 返回严格 JSON `{npc, coach, score, end}`（prompt 逻辑搬知愈 `generateTrainingPrompt`，因 ai.js 冻结，prompt 内置于 training.js）。渲染：NPC 气泡 + 小知教练点评 + 分数徽标。
- **结算**：`AI.chat` 返回 `{totalScore, rating, highlights, improvements, insight, tip}`（搬 `generateTrainingSummaryPrompt`），渲染结算卡，可存档。
- **mock 兜底**：无 Key 时用本地规则生成 NPC 回应/点评/分数与结算，保证闭环。

### B. 感官写作

- **预置场景**（搬知愈 sensory-writing.js）：雨天的忧伤 / 收到好消息 / 深夜的孤独 / 春天的期待 / 被误解的愤怒 / 安静的早晨 ＋ 自定义。
- **五感**：视/听/触/嗅/味，每感官带引导语 + 预置**词语卡片**（点选快速填入）+ 示例模板。
- **流程**：选场景 → 逐感官写（可选快速3感/完整5感）→ 拼成成品段落（本地拼接，可选 `AI.chat` 润色）→ 存档。
- **mock 兜底**：引导语用本地 `localGuides`，成品用本地拼接，无 Key 也完整。

### C. 戒指呼应（可选亮点）

对话/写作开始时，若戒指已连，触发一次 `ring.vibrate('anchor')`（吸4·呼6 共振呼吸）作为"静心入场"仪式，让修习长在硬件产品上，而非纯搬运。降级：无戒指静默跳过。

## 数据（决策：自建 `hbn.training`）

不改 store.js 冻结接口。training.js 内部封装一组小函数读写 localStorage key `hbn.training`：

```js
hbn.training  // 修习存档
[{ id, ts, kind:'dialogue'|'writing',
   title,                     // 场景标题
   // dialogue:
   score, rating, summary,    // 结算数据
   // writing:
   scenario, piece,           // 场景 + 成品段落
}]
```

读写封装在 training.js 内（`loadRecords / addRecord / delRecord`），不污染 Store 命名空间以外，不动契约。

## 错误处理

- `AI.chat` 抛错（无 Key / 网络 / 非法 JSON）→ 落到 mock 兜底路径，toast 提示"当前为离线示例"，绝不白屏。
- JSON 解析失败 → try/catch 后用降级默认值（同知愈原版做法）。
- 整页 render 出错由 index.html 的 route try/catch 兜住，不影响其他 tab。

## 验收

1. 打开 index.html → 点「修习」→ 出两张训练卡（非占位）。
2. 模拟对话：选场景→逐轮→看到 NPC+教练+分数→结算卡。
3. 感官写作：选场景→五感写作（含词语卡片）→成品段落→存档。
4. 记录页能看到存档、可查看/删除。
5. **不填 Key 全程可跑**（mock）；填 Key 用真 AI。
6. 控制台无红色报错；其他 5 个 tab 功能不受影响。

## 明确不做（YAGNI）

- 游戏化关卡地图、10 关解锁、徽章、经验条（知愈原版有，此处不搬）。
- 云函数 / 微信 API（H5 环境用 localStorage + AI.chat 替代）。
- 修改 lib/ 任何契约接口。

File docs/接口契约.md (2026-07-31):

# 接口契约 — 环抱你（所有 agent 开工前必读，不许私自改）

> 这是并行开发的"宪法"。`lib/` 共享层按此实现并冻结；`pages/*` 各 agent 只准**调用**这些接口，不准改契约。
> 改契约 = 全员返工，必须由"你（总集成）"统一修订并广播。

---

## 一、BLE 契约（固件 ↔ H5，双方必须字符串完全一致）

| 项 | 值 |
|---|---|
| Service UUID | `19b10000-e8f2-537e-4f6c-d104768a1214` |
| 心率上行 HR (Notify) | `19b10003-e8f2-537e-4f6c-d104768a1214` |
| HRV 上行 RMSSD (Notify) | `19b10005-e8f2-537e-4f6c-d104768a1214` |
| GSR 上行 (Notify, P1) | `19b10006-e8f2-537e-4f6c-d104768a1214` |
| MOTION 上行 运动量 (Notify) | `19b10007-e8f2-537e-4f6c-d104768a1214` |
| 指令下行 CMD (Write) | `19b10008-e8f2-537e-4f6c-d104768a1214` |
| GESTURE 上行 手势 (Notify) | `19b10009-e8f2-537e-4f6c-d104768a1214` |
| 广播名 | `HuanbaoNi` |

- 上行数据格式：HR = int（BPM）；HRV = float（ms, RMSSD）；GSR = int（0–4095 原始值）；
  MOTION = int（陀螺仪角速度幅度 °/s，静息个位数、晃动数百，用于 H5 运动伪迹门控 + 坐立不安信号）；
  GESTURE = 字符串 `"DBLTAP"`（双击戒指，H5 收到即 toggle 语音录音 开/关）。
- 下行指令（三档干预触觉，固件按 mode 播放不同震动序列）：
  - `"VIBRATE:INTERCEPT"` → **档三·早期拦截**：单次轻促短震（~150ms，低强度）
  - `"VIBRATE:ANCHOR"` → **档二·实时锚点**：**共振呼吸**引导，吸4·呼6（无屏息，中强度），PWM 吸气渐强、呼气渐弱，循环 3 轮
  - `"VIBRATE:RETREAT"` → **档一·撤退许可**：两下长震（长-停-长，each ~600ms，最强度）
  - `"VIBRATE"`（无参数）→ 兼容旧调用，等同 `ANCHOR`

  > **档二为何用共振呼吸（吸4·呼6）而非 4-7-8**：放松的核心生理机制是**呼气长于吸气** → 激活副交感/迷走神经 → 心率下降、HRV 上升。共振频率呼吸（约每分钟 6 次，即吸4·呼6）对 HRV 与压力恢复的研究证据最扎实（HeartMath、生物反馈治疗主流方案），且**无屏息**——对正处于急性压力中的用户最友好、最安全，正是「实时锚点」的触发场景。4-7-8 的 7 秒屏息偏重、可能对焦虑者适得其反，故不采用。震动的渐强/渐弱天然引导"吸气跟着变强、呼气跟着变弱"，比数秒更符合直觉。
- Web Bluetooth 限制：页面须 HTTPS 或 localhost；连接须由用户点击手势触发；iOS Safari 不支持。

---

## 二、统一"戒指接口"（mock.js 与 ble.js 必须实现同一套，可无缝互换）

> pages 只认这个接口，不关心背后是真硬件还是 mock。切换只改一行 `const ring = USE_MOCK ? new MockRing() : new BleRing()`。

```js
interface Ring {
  connect(): Promise<void>            // 连接（mock 立即 resolve）
  disconnect(): void
  vibrate(mode?: 'intercept'|'anchor'|'retreat'): Promise<void>  // 三档干预触觉
  onData(cb: (d: RingData) => void): void         // 实时数据回调
  onStatus(cb: (s: RingStatus) => void): void     // 状态回调
  onGesture(cb: (g: string) => void): void        // 手势回调（"DBLTAP"）
  // 仅 mock 提供，用于演示/开发：
  simulateStress?(): void             // 手动触发一次压力冲高
  simulateGesture?(g?: string): void  // 手动触发一次双击手势
}

type RingData   = { hr: number, hrv: number, gsr?: number, motion?: number, ts: number }
type RingStatus = 'idle'|'connecting'|'connected'|'baseline'|'monitoring'|'disconnected'
```

> 手势也会派发全局事件 `window` `'ring:gesture'`（`detail.gesture`），页面可二选一监听；
> 注意 ble/mock 同时触发回调与事件，页面需自行去抖（如 800ms 内只认一次）。

---

## 三、数据 Schema（localStorage，key 前缀统一 `hbn.`）

> 所有页面读写数据**只经 store.js**，不许各自直接 `localStorage.setItem`。字段冻结如下。

```js
hbn.events    // 情绪/压力事件时间线
[{ id:string, ts:number, type:'stress'|'manual',
   level:'low'|'mid'|'high', hr:number, hrv:number, gsr?:number,
   mood?:string, note?:string, source:'ring'|'user' }]

hbn.portraits // 心灵画像
[{ id:string, date:'YYYY-MM-DD', imgUrl:string /*dataURL*/,
   palette:string[], interpretation:string, moodSummary:string }]

hbn.growth    // 成长系统（沿用知愈 game-system 字段）
{ level:number, exp:number, totalExp:number, badges:string[],
  streakDays:number, lastActive:string, ringHugCount:number }

hbn.profile   // 用户画像 + 表达能力档案（搬知愈）
{ onboarding:object, expressionProfile:{strengths:[],blocks:[],practicing:[],milestones:[]} }

hbn.settings  // 运行配置
{ apiBaseUrl:string, apiKey:string, useMock:boolean }

hbn.trend     // 压力指数时间序列（24h 折线图数据源，realtime 写入）
[{ ts:number, z:number /*z-score压力指数,可正可负*/, level:'low'|'mid'|'high'|'crit' }]
```

store.js 必须导出：`getEvents/addEvent/getEventsByDate/getPortraits/addPortrait/getPortraitByDate/getGrowth/setGrowth/incRingHug/getProfile/setProfile/getSettings/setSettings/getTrend/addTrendSample`。
- `getTrend(hours=24)` 返回时间窗内样本（`hours=0` 返回全部）；`addTrendSample({z,level})` 追加一点（自动补 ts、限最近 48h/4000 点）。

---

## 四、AI 调用契约（ai.js，页面只调这三个函数）

```js
AI.config({ baseUrl, apiKey })                 // 读 hbn.settings 初始化
AI.chat(messages, { model }): Promise<string>  // 文本：小知/复盘/解读/测试分析
AI.image(prompt, { size='1024x1024' }): Promise<string /*dataURL*/>  // 心灵画像
```
- OpenAI 兼容：`fetch(baseUrl + '/chat/completions')` / `/images/generations`。
- 默认模型：chat → `gpt-5.6-sol`（兜底 DeepSeek）；image → `gpt-image-2`。
- 小知 system prompt 直接搬 `zhiyu-miniapp-1.2.0/utils/ai.js`。
- 不传敏感数据（OnePage 安全条款）。

---

## 五、设计 tokens（tokens.css，全站只用这些变量）

```css
:root{
  /* 品牌（搬知愈） */
  --bg:#FAF9F7; --accent:#D4B8A5; --ink:#3A352F; --sub:#8C8780;
  /* 压力三色（莫兰迪） */
  --calm:#A8C0B0;   /* 低 */
  --mid:#E8D4A8;    /* 中 */
  --high:#D8A08C;   /* 高 */
  /* 结构 */
  --radius:20px; --gap:16px; --shadow:0 8px 24px rgba(0,0,0,.06);
  --font: -apple-system,"PingFang SC",sans-serif;
}
```
- 圆润、柔和、留白多；不要生硬直角、不要高饱和。
- logo：知愈六瓣花；favicon + 首页 hero + 画像水印。

---

## 六、mock 数据行为（mock.js，让软件不等硬件）

- 连接后 2s 内 `onStatus('connected')` → 5s 采基线(`'baseline'`) → 之后 `'monitoring'`。
- 每 1s 推一次 `RingData`：静息 HR 68–78、HRV 40–60ms、GSR 平稳。
- `simulateStress()`：15s 内 HR 升到 95+、HRV 掉到 20 以下、GSR 抬升 → 触发一次"高压力"，页面据此发 `vibrate()` 并写 `hbn.events`。
- `vibrate()`：mock 里 console.log + 页面弹个"戒指震动"提示即可。
</content>

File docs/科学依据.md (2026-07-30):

# 科学依据 — 环抱你·情绪戒指（Demo Day 可信度材料）

> 本文件汇总「环抱你」在**输入端压力检测算法**与**输出端干预触觉**上所依据的学术文献，供路演答辩引用。
> ⚠️ 以下文献为公开检索所得，路演前请对每条的标题 / 作者 / 年份 / 结论再核对一遍原文，避免引用误差。

---

## 一、多模态生理信号做压力检测 —— 方法学范式

### WESAD 数据集（本领域最权威公开基准）
- **Schmidt, P., Reiss, A., Duerichen, R., Marberger, C., & Van Laerhoven, K. (2018).**
  *Introducing WESAD, a Multimodal Dataset for Wearable Stress and Affect Detection.*
  Proceedings of the 20th ACM International Conference on Multimodal Interaction (ICMI '18).
  DOI: 10.1145/3242969.3242985
- **要点**：WESAD 是可穿戴压力/情绪检测的标准数据集，采集的模态正是
  **BVP/ECG(心率)、EDA(皮肤电)、ACC(三轴加速度)、RESP(呼吸)、TEMP(皮温)、EMG**。
  → 证明「环抱你」选用的 **心率 + HRV + 皮肤电 + 加速度** 组合，与学术界公认的压力检测信号一致。

### 多模态融合可达高精度
- **Oliver, E., & Dakshit, S. (2025).**
  *Cross-Modality Investigation on WESAD Stress Classification.* arXiv:2502.18733.
- **要点**：在 WESAD 上用 Transformer 对上述模态做压力分类，
  准确率 / 精确率 / 召回率达 **99.73%–99.95%**。
  → 证明这套生理信号组合具备高判别力，是可行的技术路线。

---

## 二、各信号的生理学依据

### HRV（RMSSD）—— 自主神经 / 急性压力的敏感指标
- **Ernst, G. (2019).** *Heart Rate Variability—From Brain Death to Resonance Breathing at 6 Breaths per Minute.*
  Clinical Neurophysiology 系列综述。ScienceDirect: S1388245719313021
- **要点**：RMSSD 反映副交感（迷走神经）活动；急性压力 / 交感激活时 HRV 下降。
  → 「压力指数」中 **HRV 下降取正贡献** 有生理学依据。
- 补充：RMSSD 是短时程 HRV 的推荐指标（Task Force of ESC/NASPE, 1996，可作经典引用）。

### EDA / 皮肤电导 —— 情绪唤醒（arousal）的经典指标
- 皮肤电活动（Electrodermal Activity, EDA）由汗腺活动驱动，
  是交感神经唤醒的直接、经典测量（测谎、情绪研究通用）。
- 参考综述：*The Electrodermal System*（Dawson, Schell & Filion, in Handbook of Psychophysiology）。
- **要点**：情绪唤醒 → 汗腺活动 → 皮肤电导升高。
  → 「压力指数」中 **EDA 升高取正贡献** 有依据。

### 加速度（ACC）—— 运动伪迹门控 / 情境感知
- **Context-Aware Contribution in Ambulatory Electrocardiogram Measurements Using Wearable Devices**
  (Springer, 2013). DOI: 10.1007/978-3-319-00846-2_234
- **要点**：加入运动/情境信息能提升可穿戴生理信号测量的可信度。
  → 「运动闸门」（剧烈运动时降低对心率升高的压力解读权重，排除体力活动误判）方法学成立。

---

## 三、算法：个人基线 z-score 标准化 + 门控融合

**为什么不用固定阈值 / 拍脑袋权重：**
- 不同信号单位不同（心率 bpm、HRV ms、皮肤电 ADC），不能直接相加。
- 个体静息基线差异大，绝对阈值（如"心率>100=压力"）不成立。

**采用方法（对齐 WESAD 类研究的标准化特征工程）：**
1. 佩戴后采集 30–60s 静息基线，计算每路信号的均值 μ 与标准差 σ。
2. 每个采样点换算为 z-score（偏离个人基线多少个标准差）：
   - `zHR = (hr − μ_hr) / σ_hr`
   - `zHRV = (hrv − μ_hrv) / σ_hrv`（压力时取 `−zHRV`）
   - `zEDA = (eda − μ_eda) / σ_eda`
3. 压力指数 = 三路标准分等权平均：`stress = mean(zHR, −zHRV, zEDA)`
   （等权 = 不引入人为调参；亦可依文献将 HRV 略加权，作为可选项）
4. 运动门控：`stress ×= activity_factor`（剧烈运动时衰减，情境感知）；
   静止下小幅持续抖动（坐立不安）额外 +0.3。
5. **分级触发阈值 —— 采用统计过程控制(SPC)的经典分级，不是单一魔法数字**：
   - `z > 1σ` → 档三·拦截（轻提醒）：约日常尾部 16%，苗头。干预成本极低故下探到 1σ 偏向早发现。
   - `z > 2σ` → 档二·锚点（呼吸引导）：**SPC 警戒线**（~2.3%）。
   - `z > 3σ` → 档一·撤退（最强）：**SPC 报警线 / Shewhart 控制图**（~0.1%）。
   - 去抖：连续 2 次命中 + 冷却期，避免频繁打扰。

**为什么阈值这样定（诚实说明）**：
- 2σ / 3σ 是异常检测与统计过程控制（Shewhart 控制图）里的经典警戒/报警线，有出处；
  1σ 是我们在其基础上刻意往灵敏方向下探——因为干预只是一次温柔震动，代价极低，
  宁可偶尔轻提醒也不漏掉正在累积的压力（低危害 → 偏高召回）。
- **最严格的做法**是用"已知压力/非压力"标注数据画 ROC 曲线，取最大化 Youden's J 或 F1 的点做阈值；
  黑客松无标注数据，故用 SPC 分级作为有依据的默认值，并声明它是可校准的唯一参数。

**一句话答辩**：
> "我们不设绝对阈值，而是把每一路生物标志物标准化到用户个人基线的标准差单位再融合，
> 并用加速度做运动情境门控——方法学对齐 WESAD 数据集范式。触发阈值采用统计过程控制的
> 经典分级：2σ 警戒、3σ 报警，据此把干预分成三档渐进；苗头档下探到 1σ 以偏向早发现。
> 这些阈值是可按个体标注数据用 ROC 曲线进一步校准的唯一参数。"

---

## 四、输出端：档二"共振呼吸（吸4·呼6）"干预

- **Laborde, S., et al. (2022).** *Effects of voluntary slow breathing on heart rate and heart rate variability: A systematic review and a meta-analysis.* PubMed: 35623448.
  - 要点：自主慢呼吸（~6 次/分）显著提升 HR/HRV、激活副交感。
- **Meehan, Z. M., & Shaffer, F. (2024).** *Do Longer Exhalations Increase HRV During Slow-Paced Breathing?* (Europe PMC: PMC11310264)
  - 要点：呼气长于吸气更有利于 HRV 提升。
- **要点**：档二采用 **吸4·呼6（≈6次/分、呼>吸、无屏息）** 的共振呼吸引导，
  比 4-7-8（含 7s 屏息，对急性焦虑者可能不友好）更契合"实时锚点"场景。
  马达 PWM 吸气渐强 / 呼气渐弱，天然引导呼吸节律。

---

## 五、隐私 —— 数据本地化（产品差异点）

- 生理数据与录音原件全部存于用户设备本地（浏览器 localStorage / IndexedDB），
  不上传服务器。对比"面部识别情绪"方案：无摄像头、数据不出端。
- 呼应产品叙事："别人要你盯摄像头，我们连服务器都不传。"

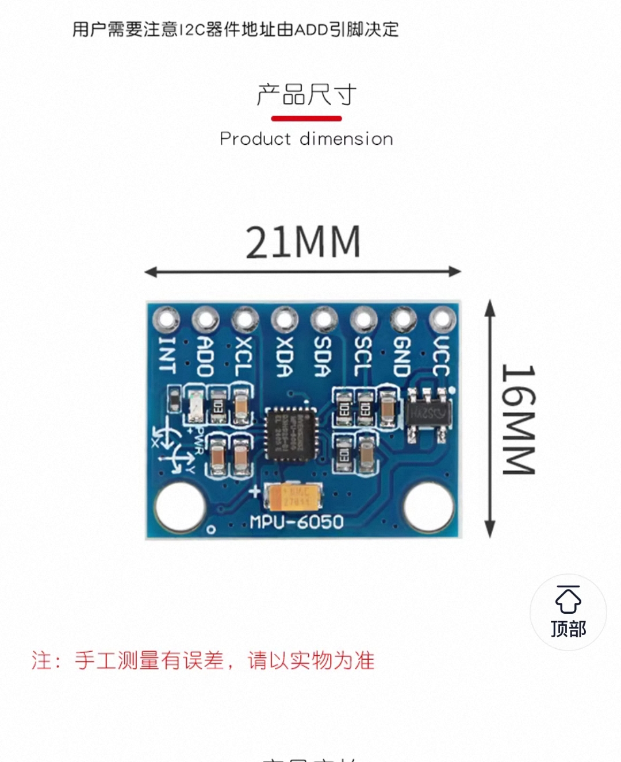
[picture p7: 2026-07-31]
docs/hardware/mpu6050.jpg

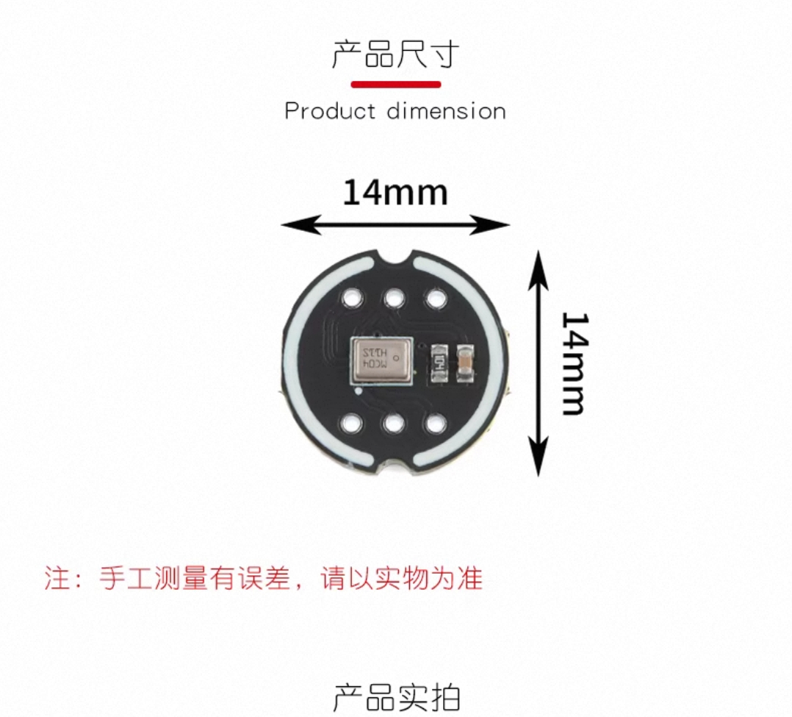
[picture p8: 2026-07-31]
docs/hardware/inmp441.jpg

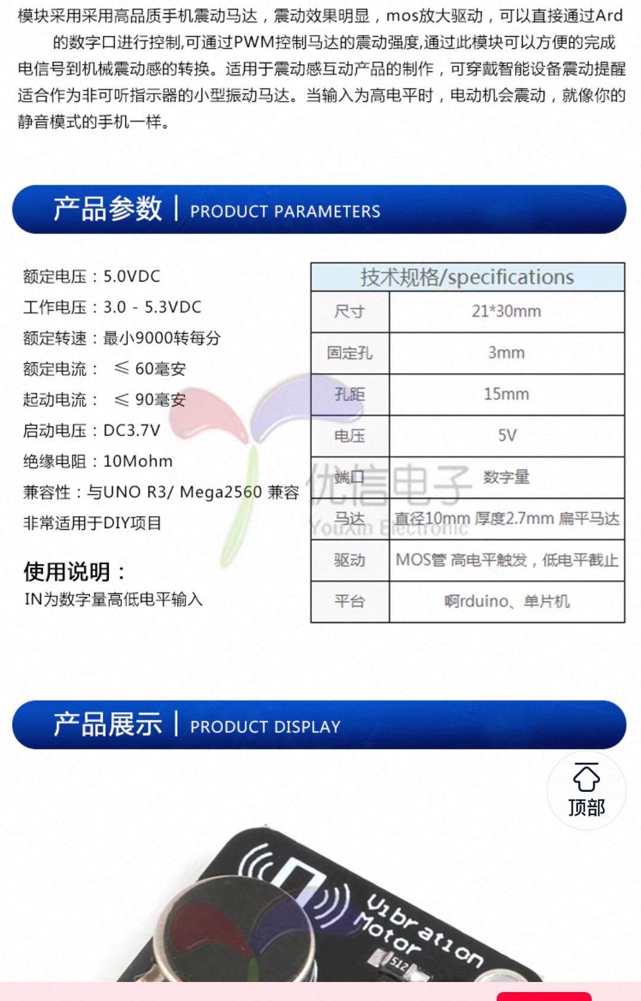
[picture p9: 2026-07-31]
docs/hardware/motor.jpg

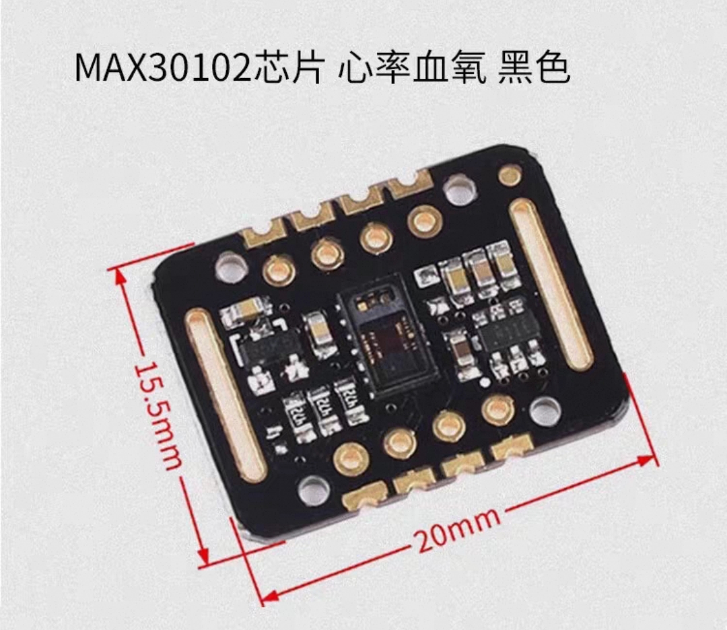
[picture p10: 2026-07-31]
docs/hardware/max30102.jpg

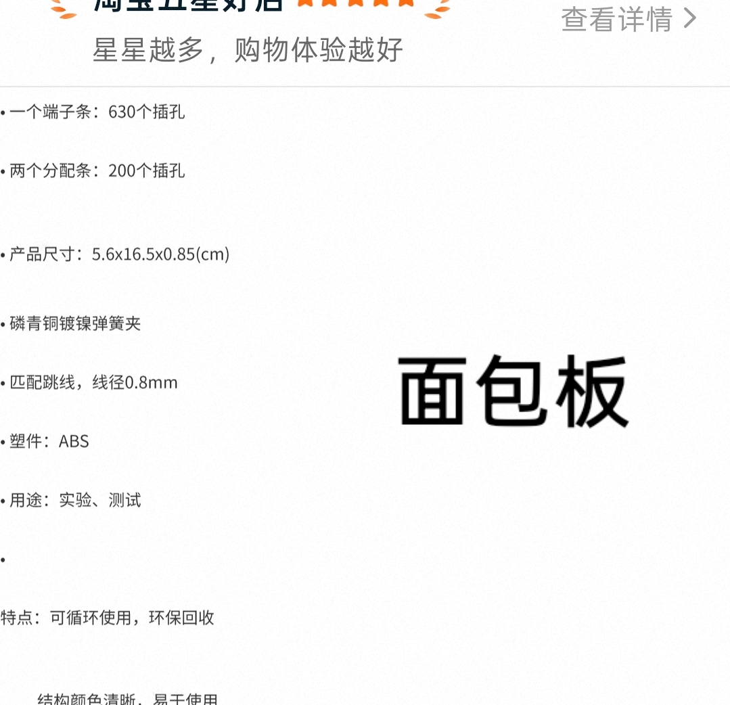
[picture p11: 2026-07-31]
docs/hardware/breadboard.jpg

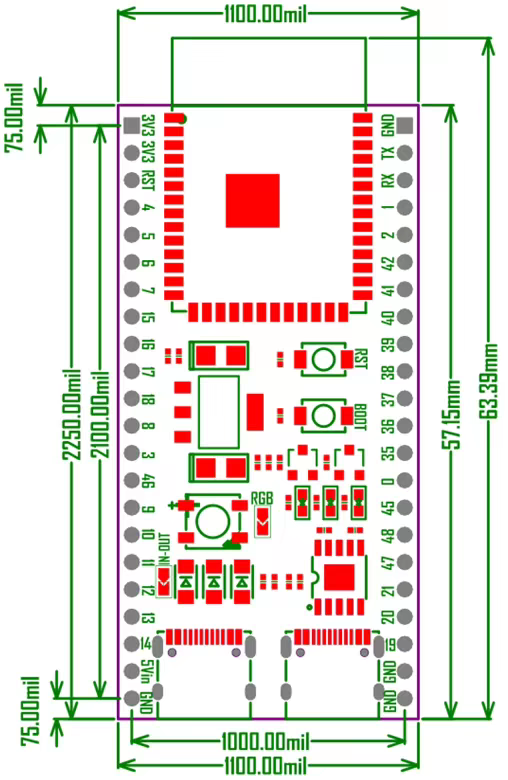
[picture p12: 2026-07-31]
docs/hardware/esp32-s3.png

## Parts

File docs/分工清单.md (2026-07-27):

# 分工清单（实时任务看板）— 环抱你

> 并行开发的"作战地图"。每个 agent 只做自己那行，只碰"文件所有权"里属于自己的文件。
> 状态标记：⬜ 未开始 / 🟨 进行中 / ✅ 完成 / 🟥 卡住(交给你)
> 更新方式：你（总集成）每完成一块就改状态 + git commit。

---

## 0. 铁律（所有 agent 通用，写进每个 agent 的 prompt 开头）
1. 先读 `docs/接口契约.md`，**严格按契约**，不许改 `lib/` 里的接口签名与数据 schema。
2. **只准编辑分配给你的文件**（见下表），不许碰别人的文件。
3. 数据只经 `store.js`，样式只用 `tokens.css` 变量，AI 只调 `ai.js`，戒指只调统一 Ring 接口。
4. 纯 HTML+CSS+vanilla JS，无框架、无构建步骤，能在 `localhost` 直接打开跑。
5. 交付前自检：能打开、控制台无报错、用了 mock 能看到数据/交互。
6. commit 信息格式：`[模块名] 做了什么`。

---

## 1. 阶段一：共享契约层（由"你"最先完成，冻结后其他人才能开工）

| 文件 | 内容 | 状态 |
|---|---|---|
| `webapp/lib/tokens.css` | 设计变量（见契约§5） | ✅ |
| `webapp/lib/store.js` | localStorage 读写（见契约§3） | ✅ |
| `webapp/lib/mock.js` | 假戒指数据源（见契约§2/§6） | ✅ |
| `webapp/lib/ble.js` | 真 Web Bluetooth（见契约§1/§2）— 硬件通了再接 | ⬜ |
| `webapp/lib/ai.js` | AI 调用（见契约§4）+ 搬知愈小知 prompt | ✅ |
| `webapp/index.html` | 6 tab 路由骨架 + 引入 lib | ✅ |

> 契约层已冻结（除 ble.js 待硬件）。软件 agent A–F 现在可以并行开工。

> 这一阶段是"卡脖子"步骤，最优先。完成前软件 agent 无法安全并行。

---

## 2. 阶段二：软件模块（阶段一冻结后，A–F 并行）

| Agent | 模块 | 文件所有权 | 依赖 | 输出/验收标准 |
|---|---|---|---|---|
| **A** | 环抱(实时主页) | `pages/realtime.js` (+`realtime.css`) | Ring接口, store, tokens | 连接按钮→仪表盘出实时HR/HRV→三色压力环；压力"高"自动 `vibrate()`+写 `hbn.events`；有"测试震动"按钮。用 mock 全流程可演示 |
| **B** | 今日心灵画像 ⭐ | `pages/portrait.js` (+css) | ai(image), store | 读当日 `hbn.events` 汇总情绪→拼 prompt→`AI.image()` 生成画→显示+解读→存 `hbn.portraits`。生成慢时可用预置样张兜底 |
| **C** | 心迹(成长轨迹) | `pages/growth.js` (+css) | store, 搬game-system | 画像画廊(色调演变) + 情绪/压力趋势图 + 等级/徽章/连续天数 + "被环抱N次" |
| **D** | 小知(AI管家) | `pages/chat.js` (+css) | ai(chat), store | 对话界面；压力事件后主动发起复盘；system prompt 搬知愈；能读 `hbn.events` 做情境化复盘 |
| **E** | 探索自己(测试) | `pages/tests.js` (+css) | ai(chat), store | HSP/压力/性格/情绪测试，选题→出结果→AI解读→存档。内容可用现成量表 |
| **F** | 修习(训练) | `pages/training.js` (+css) | ai(chat), store | 表达训练 + 感官写作，搬知愈 `subpages/training` 内容与流程 |
| **R** | 监工/QA | 只读 + 提 issue | 全部 | 按"验收标准"逐模块复查；最多 2 轮改-复查；不过标 🟥 交给你 |

> 优先级：A、B 属 **P0**（先做到完美）；C、D 属 P1；E、F 属 P2（演示级，搬知愈内容即可）。

---

## 3. 硬件轨道（你亲自，和阶段二并行）

| 里程碑 | 内容 | 验收（人工） | 状态 |
|---|---|---|---|
| M0 | Arduino 环境 + Blink | 板载灯闪 | ⬜ |
| M1 | `firmware/huanbaoni.ino`：MAX30102→HR/HRV→BLE Notify；收 "VIBRATE" 震动 | 串口出心率；发指令马达震 | 🟨 代码已写, 待硬件烧录验证 |
| M3 | 硬件 ↔ H5 联调 | realtime 页从 mock 切 `ble.js`，真实心率进仪表盘，压力→真震动 | ⬜ |
| M5+ | GSR/INMP441 加分 | 数值/氛围进界面 | ⬜ |

---

## 4. 汇合与集成（你）
- realtime 页把 `USE_MOCK=false` 切到 `ble.js` → 端到端联调（M3）。
- 全模块串成 index.html 的 6 tab → 走查一遍演示动线。
- 3D 底座/道具 + PPT + 演示视频（防翻车）。

---

## 5. 每个 agent 的启动 prompt 模板（复制即用）
```
你负责 环抱你 项目的【模块X】，只允许编辑：<该模块的文件>。
开工前必读 docs/接口契约.md，严格遵守其中 BLE/Ring接口/数据schema/tokens/AI 契约。
技术栈：纯 HTML+CSS+vanilla JS，无框架，localhost 直接可跑。
数据只经 store.js，样式只用 tokens.css 变量，AI 只调 ai.js，戒指只调统一 Ring 接口（开发期用 mock.js）。
目标与验收：<从分工表复制该模块的"输出/验收标准">。
完成后自检：能打开、控制台无报错、用 mock 能演示完整交互。
不要碰其他任何文件。
```
</content>

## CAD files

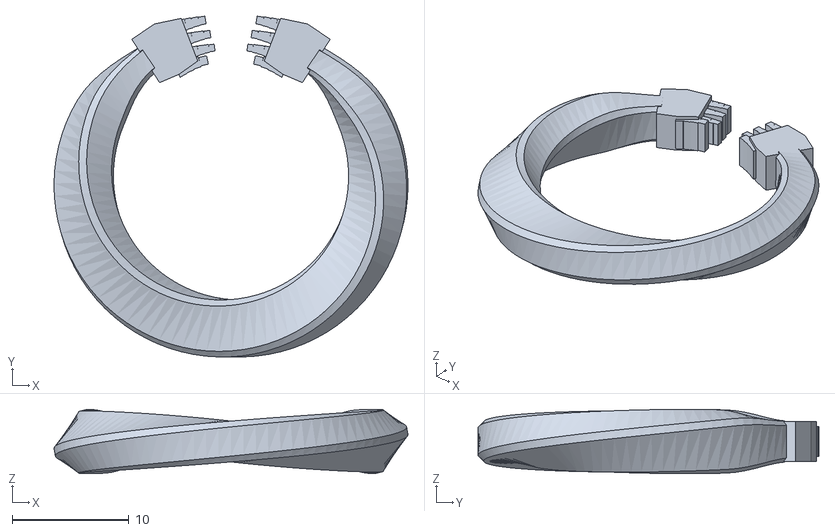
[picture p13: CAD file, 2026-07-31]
cad/output/flush_hands_v5/feelingmosaic_flush_hands_ring_18.5mm.stl
30.3 x 29.2 x 5.50

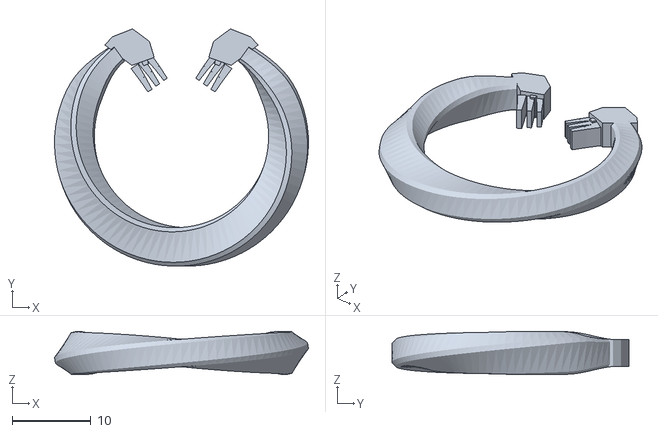
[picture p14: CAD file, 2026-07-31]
cad/output/inward_palms_v6/feelingmosaic_inward_palms_ring_20.5mm.stl
32.3 x 30.2 x 5.50

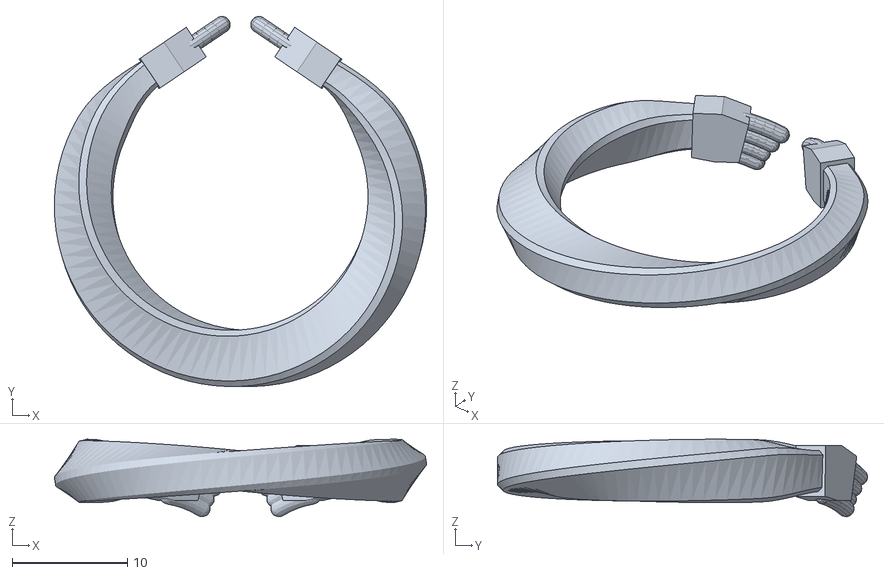
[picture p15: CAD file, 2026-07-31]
cad/output/long_round_fingers_v8/feelingmosaic_long_round_fingers_ring_20.5mm.stl
32.3 x 32.1 x 6.73

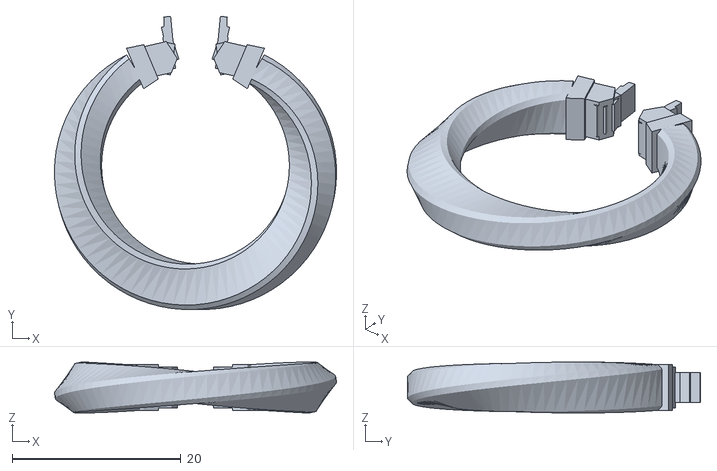
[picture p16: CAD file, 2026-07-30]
cad/output/luxury_v2/feelingmosaic_luxury_ring_20.5mm.stl
33.4 x 34.7 x 6.04

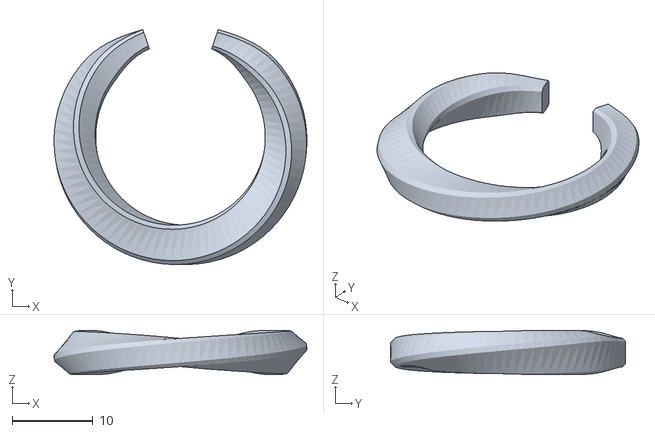
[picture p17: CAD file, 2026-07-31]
cad/output/minimal_v4/feelingmosaic_minimal_open_ring_19.5mm.stl
31.4 x 29.2 x 5.50

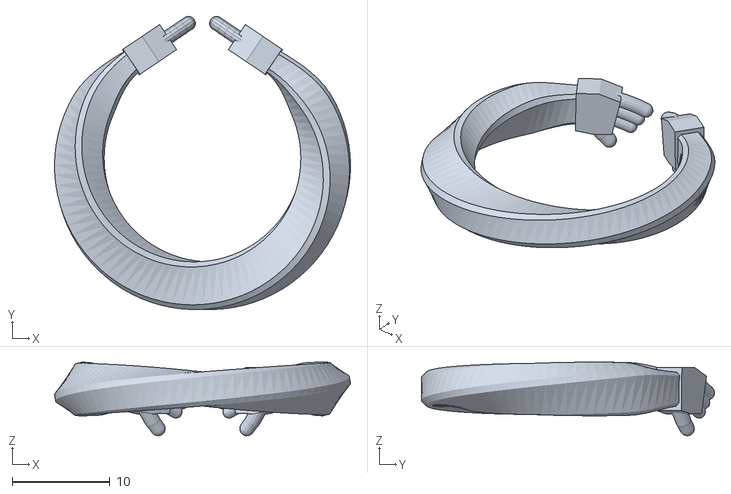
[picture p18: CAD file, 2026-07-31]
cad/output/open_thumbs_v9/feelingmosaic_open_thumbs_ring_18.5mm.stl
30.3 x 30.0 x 7.56

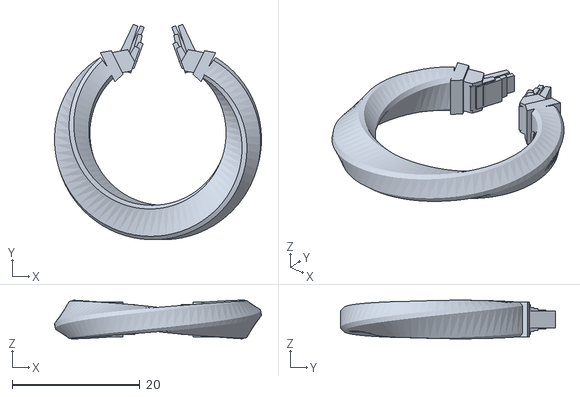
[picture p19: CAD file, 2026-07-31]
cad/output/open_v3/feelingmosaic_open_embrace_ring_19.5mm.stl
32.4 x 33.7 x 6.04

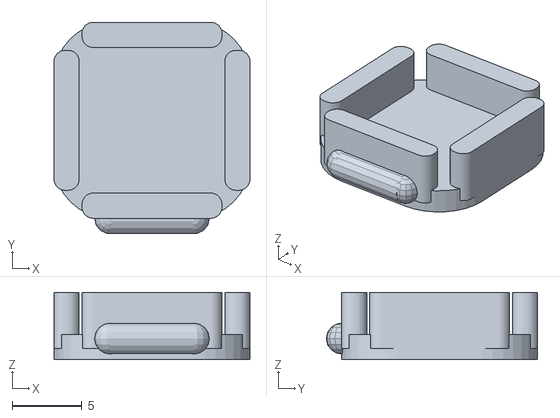
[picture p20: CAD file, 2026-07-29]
cad/output/optional_10mm_coin_motor_insert.stl
14.0 x 15.1 x 4.80

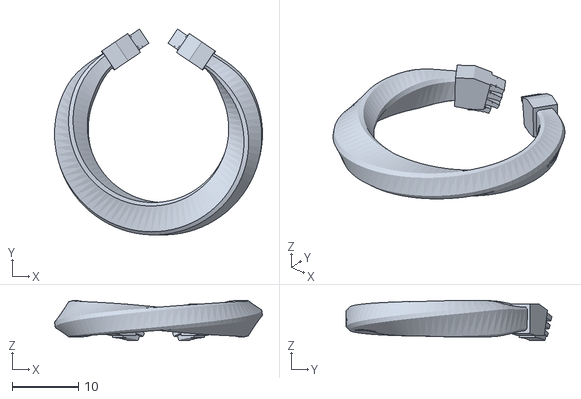
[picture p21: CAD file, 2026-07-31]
cad/output/standing_palms_v7/feelingmosaic_standing_palms_ring_19.5mm.stl
31.3 x 31.0 x 6.02

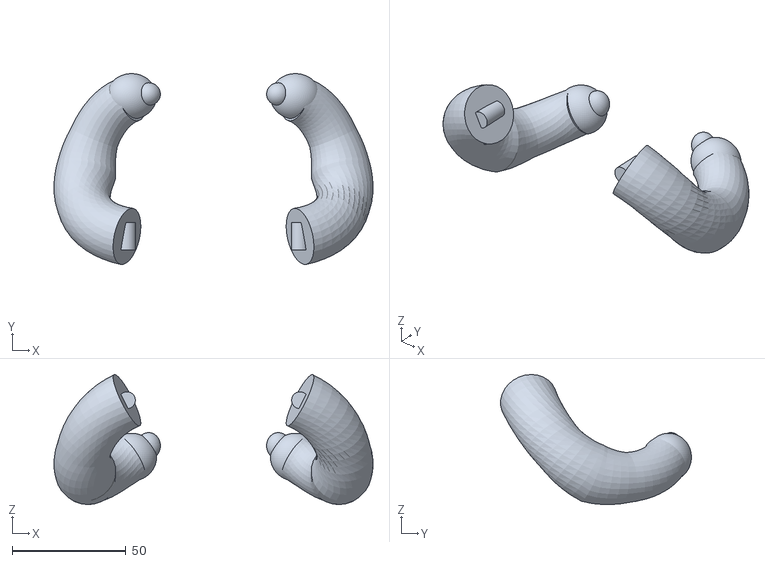
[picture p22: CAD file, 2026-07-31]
hardware/arms.stl
140.1 x 83.8 x 57.1

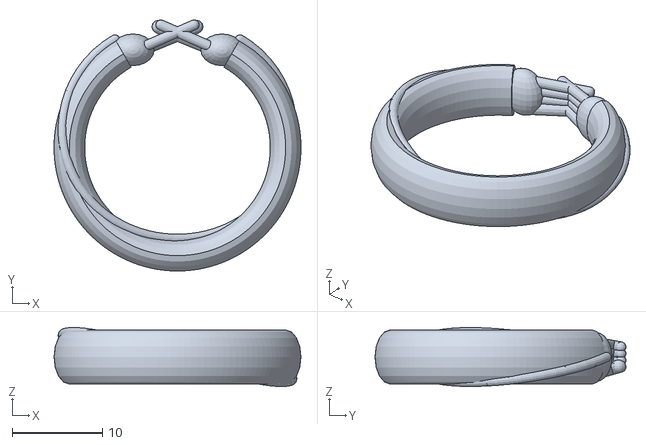
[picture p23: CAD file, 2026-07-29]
cad/output/feelingmosaic_ring_20.5mm.stl
27.3 x 27.7 x 6.54

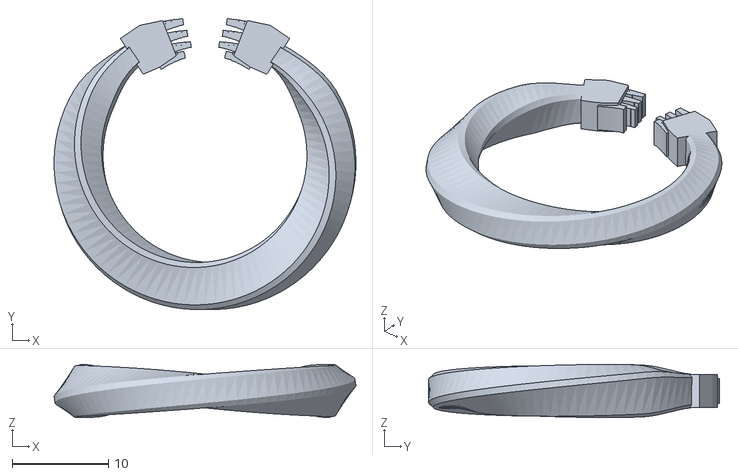
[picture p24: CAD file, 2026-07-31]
cad/output/flush_hands_v5/feelingmosaic_flush_hands_ring_19.5mm.stl
31.3 x 30.2 x 5.50

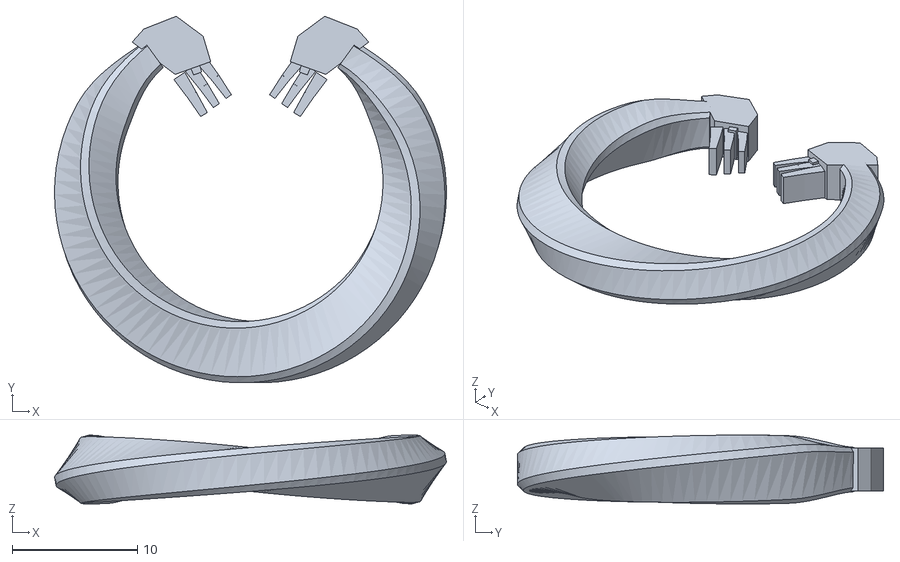
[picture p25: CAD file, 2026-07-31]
cad/output/inward_palms_v6/feelingmosaic_inward_palms_ring_19.5mm.stl
31.3 x 29.3 x 5.50

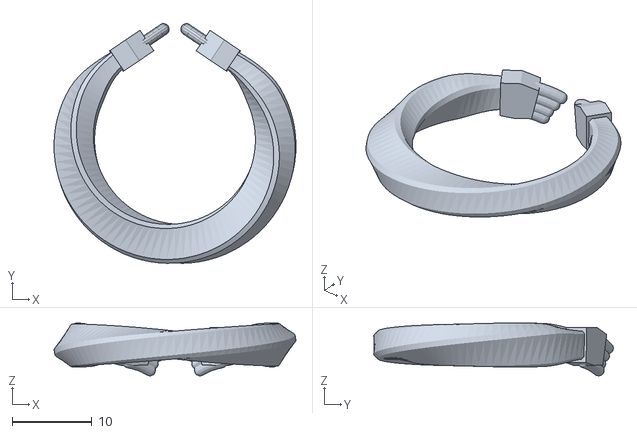
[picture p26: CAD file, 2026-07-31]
cad/output/long_round_fingers_v8/feelingmosaic_long_round_fingers_ring_18.5mm.stl
30.3 x 30.0 x 6.63

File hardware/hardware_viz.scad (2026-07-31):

// ============================================================
// 环抱你 · 硬件可视化 (for demo video)
//   模块按真实安装位摆进壳里 + 剖面 / 爆炸图
//   use enclosure.scad 的壳体, 这里只加简化模块 + 渲染编排
//   mode = ext | cut | explode
// ============================================================
use </Users/wangjiayi14/Downloads/知愈-ring真系列/huanbaoni/hardware_xiaobai/enclosure.scad>

mode = "cut";
spin = 0;    // 绕竖直轴旋转（转台动画用）
$fn = 64;

// 配色
C_WHITE = "#FBFAF7";
C_PINK  = "#E7C6AC";   // 鎏光 silk 香槟粉（手臂）
C_PCB_G = "#2E7D52";   // 面包板绿
C_PCB_K = "#1C1C22";   // ESP32 黑
C_PCB_R = "#8E2F4C";   // MAX30102 暗红
C_PCB_B = "#274B8E";   // MPU6050 蓝
C_GOLD  = "#C9A24B";   // 排针/触点金
C_COP   = "#B06B3A";   // 电极铜

// ---------- 通用零件 ----------
module pcb(w, l, t, col) {                 // 以中心为原点, 厚度沿 Y
  color(col) translate([0, -t/2, 0])
    rotate([-90,0,0]) linear_extrude(t)
      offset(r=0.8) offset(delta=-0.8) square([w, l], center=true);
}
module header(n, col=C_GOLD) {             // 一排排针, 沿 X, 朝 +Y
  color(col) for (i=[0:n-1])
    translate([(i-(n-1)/2)*2.54, 0, 0]) rotate([-90,0,0]) cylinder(h=4, d=0.9);
}

// ---------- 各模块 (原点=模块中心, 面朝 +Y 或 -Y 由摆放决定) ----------
module m_breadboard() {                     // 面包板 82x55x8.5, 竖装, 背贴后壳
  color("#EDE7D6") translate([0,-24,62]) rotate([-90,0,0])
    linear_extrude(8.5) offset(r=2) offset(delta=-2) square([55,82], center=true);
}
module m_esp32() {                          // ESP32-S3 27.9x57.2, 竖装, 前下, Type-C 朝下
  translate([0,20,30]) {
    pcb(27.9, 57.2, 1.6, C_PCB_K);
    // 双 Type-C 朝下
    color("#888") for (dx=[-6.5,6.5]) translate([dx,0,-30]) cube([8.5,3.2,6], center=true);
    // USB 屏蔽罩 + 芯片
    color("#3a3a44") translate([0,1.2,8]) cube([16,2.5,18], center=true);
  }
}
module m_max30102() {                        // 心率/HRV, 前凸台 z72, 朝 +Y
  translate([0,40,72]) {
    pcb(15.5,20,1.2,C_PCB_R);
    color("#111") translate([0,0.9,0]) cube([5.6,1.4,3.4], center=true);   // 光学窗
    translate([0,-0.9,-8]) rotate([180,0,0]) header(5);                    // 排针朝内
  }
}
module m_mpu6050() {                         // 敲击/运动, 后凸台 z82, 朝 -Y
  translate([0,-34,82]) rotate([0,0,180]) {
    pcb(16,21,1.2,C_PCB_B);
    color("#222") translate([0,-0.9,0]) cube([3,1.2,3], center=true);
    translate([0,-0.9,-9]) rotate([180,0,0]) header(8);
  }
}
module m_gsr() {                             // 皮肤电模块, 壳内(挂面包板前)
  translate([16,-14,40]) { pcb(20,32,1.2,"#3E6B8E"); }
}
module m_mic() {                             // INMP441 麦克风
  translate([-18,-14,44]) { pcb(14,18,1.2,"#4A4A55"); }
}

// ---------- 外接指套 (GSR 正负极板 + 振动马达) ----------
module finger_cuff(open=0) {
  // C 形指套, 放在盒子前方
  translate([0, 78 + open, 40]) {
    color(C_WHITE) rotate([90,0,0])
      rotate_extrude(angle=280, $fn=64) translate([12,0]) circle(d=9);
    // 正负极板
    color(C_COP) translate([-6,0,-11]) cube([9,5,1.2], center=true);   // +
    color("#9AA0A6") translate([6,0,-11]) cube([9,5,1.2], center=true); // -
    // 振动马达 coin
    color("#5b5b66") translate([0,0,12]) rotate([90,0,0]) cylinder(h=2.7,d=10, center=true);
  }
}

// ---------- 线缆 (背面孔 -> 指套) ----------
module wires() {
  color("#C86B7A") for (dx=[-7,7])
    translate([dx,-44,50]) rotate([-90,0,0]) cylinder(h=6,d=2.4);
}

// ---------- 内部模块合集 ----------
module internals() {
  m_breadboard(); m_esp32(); m_max30102(); m_mpu6050(); m_gsr(); m_mic();
}

// ---------- 渲染编排 ----------
module shell_front(a=1) { color(C_WHITE, a) body_front(); }
module shell_back(a=1)  { color(C_WHITE, a) body_back(); }
module the_arms(a=1)    { color(C_PINK, a) arms(); }

rotate([0,0,spin]) scene();
module scene() {
if (mode == "ext") {
  shell_front(); shell_back(); the_arms();
} else if (mode == "cut") {
  // 开壳剖切: 后半壳作碗底(实), 手臂淡出作框, 内部模块实心露出
  shell_back();
  the_arms(0.4);
  internals();
  wires();
  finger_cuff();
} else if (mode == "cut_wedge") {
  difference() {
    union() { shell_front(); shell_back(); the_arms(); }
    translate([0, 0, -20]) cube([140, 140, 340]);
  }
  internals();
  wires();
  finger_cuff();
} else if (mode == "explode") {
  shell_back();  the_arms();
  translate([0,  80, 0]) shell_front();
  translate([0, 150, 0]) m_max30102();
  translate([0,-110, 0]) m_mpu6050();
  m_breadboard();
  translate([0,  55, -6]) m_esp32();
  translate([ 70, 6, 0]) m_gsr();
  translate([-70, 6, 0]) m_mic();
  finger_cuff(140);
  wires();
} else if (mode == "explode_old") {
  shell_back();  the_arms();
  translate([0, 60, 0]) shell_front();
  translate([0, 90, 0]) m_max30102();
  translate([0,-70, 0]) m_mpu6050();
  m_breadboard();
  translate([0, 40, 0]) m_esp32();
  translate([40,10,0]) m_gsr();
  translate([-40,10,0]) m_mic();
  finger_cuff(60);
  wires();
}
}

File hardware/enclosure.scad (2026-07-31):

// ============================================================
// 环抱你 · 小白 — true 3D character enclosure
//
// The electronics are hidden inside a rounded humanoid torso.
// A 56 x 83 mm half breadboard mounts vertically in the belly.
// This is not a decorated box: every external silhouette is character form.
// ============================================================

show = "assembled";
$fn = 96;
$fn_arm = 72;

// ---------- Minimum electronics envelope ----------
cavity_w = 62; // half breadboard width + tolerance
cavity_d = 32; // original 32 mm component/wiring depth
cavity_h = 90; // 83 mm breadboard + end clearance
cavity_z = 62;
wall = 2.4;
fit_tol = 0.35;

// Hand interaction: clear slot between belly and forearms. A palm slides in
// from below/front, presses MAX30102, and is gently hugged at both edges.
hand_clearance = 22;

// ---------- Existing functional interfaces (sizes unchanged) ----------
usb_port_w = 11;
usb_port_h = 6;
usb_center_spacing = 13;
usb_center_z = -2;
esp_board_l = 63.3;
esp_board_w = 27.9;
esp_plane_y = 9;

wire_hole_d = 9;
wire_hole_gap = 14;
wire_hole_z = 50;

max_bw = 15.5;
max_bl = 20;
max_recess_d = 1.2;
max_open_w = 17;
max_bridge_w = 4.5;
max_slot_l = 20;
max_z = 72;

mpu_bw = 16;
mpu_bl = 21;
mpu_recess_d = 1.2;
mpu_slot_w = 5;
mpu_slot_l = 22;
mpu_edge_off = 5;
mpu_z = 82;

// Flat sensor bosses: a small platform stands proud of the curved belly so the
// board + pin header seat squarely and every opening penetrates cleanly.
max_face_y = 45;   // front MAX30102 boss outer flat face (belly ~43.4 here)
mpu_face_y = -39;  // back  MPU6050  boss outer flat face (belly ~-37.6 here)

// ============================================================
// Primitives
module ellipsoid(pos, radii, fn = $fn) {
  translate(pos) scale(radii) sphere(r = 1, $fn = fn);
}

module rounded_box(size, r, center = true) {
  sx = size[0]; sy = size[1]; sz = size[2];
  translate(center ? [0, 0, 0] : [sx / 2, sy / 2, sz / 2])
    hull()
      for (x = [-sx / 2 + r, sx / 2 - r])
        for (y = [-sy / 2 + r, sy / 2 - r])
          for (z = [-sz / 2 + r, sz / 2 - r])
            translate([x, y, z]) sphere(r = r, $fn = 28);
}

module capsule_2d(len, width) {
  hull() {
    translate([-len / 2, 0]) circle(d = width);
    translate([ len / 2, 0]) circle(d = width);
  }
}

module rounded_plate(w, d, h, r, pos) {
  translate(pos)
    hull()
      for (x = [-w / 2 + r, w / 2 - r])
        for (z = [-h / 2 + r, h / 2 - r])
          translate([x, 0, z])
            rotate([90, 0, 0]) cylinder(h = d, r = r, center = true, $fn = 28);
}

module heart_2d(w, h) {
  scale([w / 28, h / 28])
    union() {
      hull() {
        translate([-6.3, 5]) circle(r = 7.2, $fn = 36);
        translate([0, -10]) circle(r = 1.2, $fn = 24);
      }
      hull() {
        translate([6.3, 5]) circle(r = 7.2, $fn = 36);
        translate([0, -10]) circle(r = 1.2, $fn = 24);
      }
    }
}

module heart_plate(w, d, h, pos) {
  translate(pos)
    rotate([90, 0, 0])
      linear_extrude(d, center = true)
        heart_2d(w, h);
}

function unit(v) = v / norm(v);
function bezier3(p0, p1, p2, p3, t) =
  p0 * pow(1 - t, 3) +
  p1 * (3 * pow(1 - t, 2) * t) +
  p2 * (3 * (1 - t) * t * t) +
  p3 * (t * t * t);

function arm_center(s, t, palm_y) =
  t <= 0.5
    ? let(u = t * 2,
          p = bezier3([38, 4, 98], [54, 7, 91], [61, 17, 73], [56, 32, 66], u))
      [s * p[0], p[1], p[2]]
    : let(u = (t - 0.5) * 2,
          p = bezier3([56, 32, 66], [55, 47, 61], [47, palm_y - 3, 66], [36, palm_y, 73], u))
      [s * p[0], p[1], p[2]];

function arm_radius(t) =
  12.6 - 2.4 * t + max(0, 1.9 * (1 - abs(t - 0.5) / 0.18));

// A true continuous swept mesh. Unlike adjacent sphere hulls, this produces
// no conical section boundaries along the arm.
module smooth_arm_tube(s, palm_y, steps = 28, sides = 28) {
  centers = [for (i = [0 : steps]) arm_center(s, i / steps, palm_y)];
  tangents = [
    for (i = [0 : steps])
      unit(i == 0
        ? centers[1] - centers[0]
        : i == steps
          ? centers[steps] - centers[steps - 1]
          : centers[i + 1] - centers[i - 1])
  ];
  normals = [for (t = tangents) unit(cross(t, [0, 0, 1]))];
  binormals = [for (i = [0 : steps]) unit(cross(normals[i], tangents[i]))];

  ring_vertices = [
    for (i = [0 : steps])
      for (j = [0 : sides - 1])
        let(a = 360 * j / sides,
            r = arm_radius(i / steps))
          centers[i] + r * (cos(a) * normals[i] + sin(a) * binormals[i])
  ];
  start_center = len(ring_vertices);
  end_center = start_center + 1;
  side_faces = [
    for (i = [0 : steps - 1])
      for (j = [0 : sides - 1])
        each [
          [i * sides + j,
           i * sides + (j + 1) % sides,
           (i + 1) * sides + (j + 1) % sides],
          [i * sides + j,
           (i + 1) * sides + (j + 1) % sides,
           (i + 1) * sides + j]
        ]
  ];
  cap_faces = concat(
    [for (j = [0 : sides - 1]) [start_center, (j + 1) % sides, j]],
    [for (j = [0 : sides - 1])
      [end_center, steps * sides + j, steps * sides + (j + 1) % sides]]
  );

  polyhedron(points = concat(ring_vertices, [centers[0], centers[steps]]),
             faces = concat(side_faces, cap_faces),
             convexity = 12);
}

// Smooth Catmull-Rom body profile sampled densely before rotate_extrude.
// [radius, z] pairs; no planar front/back/side surfaces exist in this body.
body_profile = [
  [10.000,-5.000],[11.312,-4.585],[13.055,-4.086],[15.130,-3.497],
  [17.438,-2.812],[19.878,-2.026],[22.352,-1.133],[24.759,-0.126],
  [27.000,1.000],[29.180,2.235],[31.438,3.570],[33.727,5.011],
  [36.000,6.562],[38.211,8.231],[40.312,10.023],[42.258,11.944],
  [44.000,14.000],[45.542,16.201],[46.930,18.547],[48.181,21.025],
  [49.312,23.625],[50.343,26.334],[51.289,29.141],[52.169,32.033],
  [53.000,35.000],[53.794,38.122],[54.539,41.445],[55.218,44.905],
  [55.812,48.438],[56.306,51.978],[56.680,55.461],[56.917,58.823],
  [57.000,62.000],[56.903,65.003],[56.633,67.898],[56.218,70.704],
  [55.688,73.438],[55.071,76.116],[54.398,78.758],[53.698,81.380],
  [53.000,84.000],[52.289,86.657],[51.531,89.352],[50.727,92.042],
  [49.875,94.688],[48.977,97.247],[48.031,99.680],[47.039,101.944],
  [46.000,104.000],[44.935,105.826],[43.852,107.453],[42.733,108.916],
  [41.562,110.250],[40.321,111.490],[38.992,112.672],[37.558,113.830],
  [36.000,115.000],[34.314,116.178],[32.516,117.328],[30.615,118.439],
  [28.625,119.500],[26.557,120.498],[24.422,121.422],[22.232,122.260],
  [20.000,123.000],[17.555,123.635],[14.812,124.172],[11.914,124.623],
  [9.000,125.000],[6.211,125.314],[3.688,125.578],[1.570,125.803],
  [0.000,126.000]
];

// ============================================================
// Organic character volumes
module torso_outer() {
  // One continuous surface of revolution, then gently flattened front/back.
  // This gives a low round belly and narrow shoulders with continuous curvature.
  translate([0, 2, 0])
    scale([1, 0.74, 1])
      rotate_extrude(convexity = 10, $fn = 128)
        polygon(points = concat([[0, -5]], body_profile));
}

module torso_inner() {
  // Scaled organic core. Pushed closer to 1.0 to thin the belly shell from
  // ~4 mm to ~2.8 mm (large print-time/material save) while extremities stay
  // >=1.5 mm. wall_check must remain empty (electronics + 2.4 mm still fit).
  translate([0, 2, 62])
    scale([0.95, 0.935, 0.95])
      translate([0, -2, -62]) torso_outer();
}

module electronics_cavity(extra = 0) {
  translate([0, 2, cavity_z])
    rounded_box([cavity_w + 2 * extra,
                 cavity_d + 2 * extra,
                 cavity_h + 2 * extra],
                4 + extra);
}

module esp32_bay(extra = 0) {
  // Vertical lower-belly bay. PCB long axis follows Z, with the two Type-C
  // connectors on the short edge pointing straight down between the feet.
  translate([0, esp_plane_y, 27])
    rounded_box([32 + 2 * extra, 10 + 2 * extra, 64 + 2 * extra], 2 + extra);
}

module all_electronics_clearance(extra = 0) {
  union() {
    electronics_cavity(extra);
    esp32_bay(extra);
  }
}

module head_outer() {
  union() {
    // Faceless and earless: identity comes entirely from the embrace gesture.
    ellipsoid([0, 0, 134], [19, 16, 14.5]);
    ellipsoid([0, 0, 121.5], [8.5, 8.5, 6], 40);
  }
}

module head() {
  head_outer();
}

module head_inner() {
  ellipsoid([0, -1, 134], [16, 13, 11.5]);
}
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

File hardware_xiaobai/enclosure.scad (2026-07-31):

// ============================================================
// 知愈·Ring「环抱你」演示外壳  enclosure.scad
// —— 小白人形版 (chubby humanoid「小白」) ——
// 前后对开抽壳身体 + 小头 + 两只香槟环抱手臂 + 两只脚
//   · 正面(+Y) : MAX30102 心率 工字开口(卡入胸口) + 「环抱你」凹刻
//   · 背面(-Y) : MPU6050 运动 一字开口 + 2 圆形出线孔
//   · 脚底(-Z) : 双 Type-C
// 缝在 y=0 前后对开: 前壳=body_front(+Y) 后壳=body_back(-Y)
//
// 用法:
//   openscad -o lid.stl  -D 'show="body_front"' enclosure.scad   (前壳, 兼容旧名 lid)
//   openscad -o tray.stl -D 'show="body_back"'  enclosure.scad   (后壳, 兼容旧名 tray)
//   openscad -o arms.stl -D 'show="arms"'       enclosure.scad
//   openscad -o print_all.stl -D 'show="print"' enclosure.scad
//   预览: -D 'show="assembled"'
//   校核: show="wall_check"(空=壁不侵占电子腔) / "cavity_check"
// 基调: 圆润莫兰迪、含蓄有机、肥嘟嘟好抱。
// ============================================================

show = "assembled";
$fn  = 64;

// ---------- 身体(躯干椭球) ----------
torso_rx = 54;   // 半宽 → 宽 108
torso_ry = 40;   // 半深 → 深 80 (肥嘟嘟, 最大瘦身杠杆)
torso_rz = 64;   // 半高 → 躯干高 128
torso_cz = 64;   // 中心高(底≈0)

// 抽壳内腔(缩放躯干) —— 薄壁省打印时间, 电子腔仍够
inner_sx = 0.95; // 壁≈2.7mm
inner_sy = 0.935;// 壁≈2.6mm (腹深方向)
inner_sz = 0.95;

// ---------- 头 ----------
head_c   = [0, -2, 128];
head_ro  = [20, 17, 15];   // 外
head_ri  = [16, 13, 11.5]; // 内(中空, 与躯干连通)

// ---------- 脚 ----------
foot_dx  = 20;   // 左右脚中心距中线
foot_c_z = 3;
foot_r   = [13, 16, 7];

// ---------- 正面 MAX30102 心率 (工字) ----------
max_z        = 72;    // 胸口高度
max_bw       = 15.5;  max_bl = 20;   // 板 宽×长
max_open_w   = 17;    // 两排针总开口宽
max_bridge_w = 4.5;   // 中间支撑柱宽
max_slot_l   = 20;    // 单侧通槽长
max_recess_d = 1.4;   // 板嵌入浅槽深

// ---------- 背面 MPU6050 运动 (一字) ----------
mpu_z        = 82;
mpu_bw       = 16;   mpu_bl = 21;
mpu_slot_w   = 5;    mpu_slot_l = 22;
mpu_edge_off = 5;    // 槽中心偏到一条边
mpu_recess_d = 1.4;

// boss(凸台)外/内 y 平面(足够穿越腹壁, 保证凸出+通透)
front_boss_out = 47;  front_boss_in = 26;
back_boss_out  = -47; back_boss_in  = -26;

// ---------- 背面出线孔 ×2 (GSR + 马达) ----------
wire_d   = 9;
wire_z   = 34;
wire_gap = 14;

// ---------- 脚底双 Type-C ----------
usb_w = 11; usb_h = 6; usb_gap = 13; usb_z = 12; usb_y = 14;

// ---------- 刻字 ----------
font_cn   = "Heiti SC";
hero_txt  = "环抱你";
hero_size = 5.5;
hero_z    = 52;      // 胸口 MAX 下方
engrave_d = 1.5;

// ---------- 手臂(分体, 香槟色) ----------
arm_z0    = 88;      // 肩根高
$fn_arm   = 40;

// ============================================================
// 基元
module ellipsoid(c, r) { translate(c) scale(r) sphere(r = 1, $fn = $fn); }

module rounded_box(sz, r = 3) {
  hull() for (x = [-1,1]) for (y = [-1,1]) for (z = [-1,1])
    translate([x*(sz[0]/2 - r), y*(sz[1]/2 - r), z*(sz[2]/2 - r)])
      sphere(r = r, $fn = 24);
}

// 前/后凸台(从腹内穿到腹外, 保证凸出且可开通槽)
module front_boss() {
  translate([0, (front_boss_out + front_boss_in)/2, max_z])
    rounded_box([24, front_boss_out - front_boss_in, 30], 4);
}
module back_boss() {
  translate([0, (back_boss_out + back_boss_in)/2, mpu_z])
    rounded_box([26, back_boss_in - back_boss_out, 31], 4);
}

// ---------- 身体实体(外) ----------
module body_outer() {
  union() {
    ellipsoid([0,0,torso_cz], [torso_rx, torso_ry, torso_rz]);
    ellipsoid(head_c, head_ro);
    for (s = [-1,1]) ellipsoid([s*foot_dx, 0, foot_c_z], foot_r);   // 脚居中跨缝(前后各半, 不留浮件)
    front_boss();
    back_boss();
  }
}
// ---------- 身体内腔(中空) ----------
module body_inner() {
  union() {
    ellipsoid([0,0,torso_cz], [torso_rx*inner_sx, torso_ry*inner_sy, torso_rz*inner_sz]);
    ellipsoid(head_c, head_ri);
  }
}

// ---------- 功能开口 ----------
// 正面 MAX 工字: 板浅槽 + 中柱两侧通槽
module max_cuts() {
  sw = (max_open_w - max_bridge_w)/2;
  // 板嵌入浅槽(从外表面下沉)
  translate([0, front_boss_out - max_recess_d/2, max_z])
    rounded_box([max_bw + 2, max_recess_d + 0.1, max_bl + 2], 0.8);
  // 两侧穿透通槽
  for (side = [-1,1]) {
    cx = side*(max_bridge_w/2 + sw/2);
    translate([cx, (front_boss_out + front_boss_in)/2, max_z])
      cube([sw, (front_boss_out - front_boss_in) + 30, max_slot_l], center = true);
  }
}
// 背面 MPU 一字: 板浅槽 + 单边通槽
module mpu_cuts() {
  translate([0, back_boss_out + mpu_recess_d/2, mpu_z])
    rounded_box([mpu_bw + 2, mpu_recess_d + 0.1, mpu_bl + 2], 0.8);
  translate([mpu_edge_off, (back_boss_out + back_boss_in)/2, mpu_z])
    cube([mpu_slot_w, (back_boss_in - back_boss_out) + 30, mpu_slot_l], center = true);
}
// 背面出线孔
module wire_holes() {
  for (dx = [-wire_gap/2, wire_gap/2])
    translate([dx, 0, wire_z]) rotate([90,0,0]) cylinder(h = 120, d = wire_d, center = true);
}
// 脚底双 Type-C(竖直穿底)
module usb_holes() {
  for (dx = [-usb_gap/2, usb_gap/2])
    translate([dx, usb_y, usb_z]) rotate([0,0,0])
      cube([usb_w, usb_h, 40], center = true);
}
// 正面胸口刻字(镜像修正朝外正读)
module engrave_text() {
  translate([0, front_boss_out - 6, hero_z]) rotate([90,0,0])
    linear_extrude(height = engrave_d + 4)
      mirror([1,0,0]) text(hero_txt, size = hero_size, font = font_cn,
                           halign = "center", valign = "center", spacing = 1.05);
}

// ============================================================
// 前壳 / 后壳 (y=0 对开)
module body_hollow() { difference() { body_outer(); body_inner(); } }

module body_front() {
  difference() {
    intersection() {
      body_hollow();
      translate([-200, 0, -60]) cube([400, 300, 320]);   // 保留 y>=0
    }
    max_cuts();
    engrave_text();
    usb_holes();      // Type-C 在前底
  }
}
module body_back() {
  difference() {
    intersection() {
      body_hollow();
      translate([-200, -300, -60]) cube([400, 300, 320]); // 保留 y<=0
    }
    mpu_cuts();
    wire_holes();
  }
}

// ============================================================
// 手臂: 沿路径球体 hull → 光滑锥形; 连指手套手掌
module limb(pts, rads) {
  for (i = [0:len(pts)-2])
    hull() {
      translate(pts[i])   sphere(r = rads[i],   $fn = $fn_arm);
      translate(pts[i+1]) sphere(r = rads[i+1], $fn = $fn_arm);
    }
}
module hand(pos, r, s) {
  translate(pos) {
    scale([1.35, 1.0, 0.62]) sphere(r = r, $fn = $fn_arm);
    translate([-s*r*0.4, r*0.35, 0]) scale([0.65,0.9,0.55]) sphere(r = r*0.62, $fn = $fn_arm);
  }
}
// s=+1 右臂(从 +x 肩), s=-1 左臂; 翻到正面(+Y)相拥
module arm(s) {
  sx = s*torso_rx*0.82;
  pts = [
    [sx,          6,   arm_z0],       // 肩根(贴体侧, 略偏前)
    [sx + s*3,    20,  arm_z0-4],     // 上臂外鼓
    [s*38,        36,  arm_z0-14],    // 肘(向前包)
    [s*20,        46,  arm_z0-24],    // 前臂
    [s*7,         49,  arm_z0-30],    // 腕
  ];
  rads = [6.4, 6.0, 5.2, 4.4, 3.8];
  union() {
    limb(pts, rads);
    hand([s*2, 50, arm_z0-31], 6, s); // 双手在正中相扣
  }
}
module arms() { arm(1); arm(-1); }

// ============================================================
module assembled() {
  color("#FBFAF7") body_front();
  color("#FBFAF7") body_back();
  color("#E3D0A0") arms();          // 香槟色手臂
}

// 手臂平躺(便于无支撑打印)
module arm_flat(s) { translate([0, 34, -(arm_z0-31)]) rotate([90,0,0]) arm(s); }

// 打印排版: 前壳开口朝上 + 后壳开口朝上 + 两臂侧躺, 间距≥18
module print_layout() {
  rotate([-90,0,0]) body_back();                 // 后壳躺平(腔朝上)
  translate([130,0,0]) rotate([90,0,0]) body_front();
  translate([60, 100, 0]) arm_flat(1);
  translate([60, 130, 0]) arm_flat(-1);
}

// ============================================================
if      (show == "body_front")  body_front();
else if (show == "body_back")   body_back();
else if (show == "arm")         arm(1);
else if (show == "arm_l")       arm(-1);
else if (show == "arms")        arms();
else if (show == "assembled")   assembled();
else if (show == "print")       print_layout();
else if (show == "wall_check")
  // 内腔壳应不侵占电子腔: 内壳 与 电子包络 的交集应为空
  intersection() {
    difference() { body_outer(); body_inner(); }              // 壳体
    ellipsoid([0,0,torso_cz], [27.5, 4.5, 45]);               // 立式面包板+ESP 包络(半尺寸)
  }
else if (show == "cavity_check")
  intersection() {
    body_inner();
    translate([-100, -100, -60]) cube([200, 100, 320]);       // 剖开看腔
  }
else assembled();

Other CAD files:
cad/output/luxury_v2/luxury_open_display_frame.stl
cad/output/minimal_v4/feelingmosaic_minimal_open_ring_18.5mm.stl
cad/output/open_thumbs_v9/feelingmosaic_open_thumbs_ring_19.5mm.stl
cad/output/open_v3/feelingmosaic_open_embrace_ring_18.5mm.stl
cad/output/electronics_tray_140x95.obj
cad/output/electronics_tray_140x95.stl
cad/output/feelingmosaic_ring_18.5mm.obj
cad/output/feelingmosaic_ring_18.5mm.stl
cad/output/feelingmosaic_ring_19.5mm.obj
cad/output/feelingmosaic_ring_19.5mm.stl
cad/output/feelingmosaic_ring_20.5mm.obj
cad/output/flush_hands_v5/feelingmosaic_flush_hands_ring_18.5mm.obj
cad/output/flush_hands_v5/feelingmosaic_flush_hands_ring_19.5mm.obj
cad/output/flush_hands_v5/feelingmosaic_flush_hands_ring_20.5mm.obj
cad/output/flush_hands_v5/feelingmosaic_flush_hands_ring_20.5mm.stl
cad/output/inward_palms_v6/feelingmosaic_inward_palms_ring_18.5mm.obj
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

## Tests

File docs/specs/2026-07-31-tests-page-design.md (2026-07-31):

# 「探索」页设计（环抱你 H5 · Agent E）

> 2026-07-31。落地 index.html 第 5 个 tab `tests`（label「探索」），目前为占位。
> 对应 [分工清单.md](../分工清单.md) Agent E：`pages/tests.js`，「探索自己(测试)：HSP/压力/性格/情绪测试，选题→出结果→AI解读→存档。内容可用现成量表」。

## 目标

在 `huanbaoni/webapp` 里实现「探索」页，把两套**有学术出处的公开心理量表**做成 vanilla-JS 自测闭环：

1. **高敏感自测（HSPS-12）** — 主打，契合产品对高敏感人群(HSP)的定位。
2. **压力自测（PSS-10）** — 呼应戒指「测压力」主题。

流程统一：选量表 → 逐题作答 → 本地计分（含反向题）→ 结果页（分数 + 分段解释 + 小知 AI 解读 + 存档）→ 可回看历史。

## 硬约束：题目必须有出处，不许编造

用户明确要求：**题目必须来自已发表量表/论文，不允许随便乱编**。因此本页所有题目、计分、分级都必须可溯源，代码里每套量表带 `source`（引用）与逐题 `en`（英文原文）字段。核证结论如下（两个调研 subagent 已逐字核实原始 PDF）：

### 量表一：HSPS 高敏感人格量表

- **出处**：Aron, E. N., & Aron, A. (1997). *Sensory-processing sensitivity and its relation to introversion and emotionality.* Journal of Personality and Social Psychology, 73(2), 345–368. DOI: 10.1037/0022-3514.73.2.345。27 题英文原文已逐字核实（官方 hsperson.com 论文 PDF Table 1）。
- **采用**：**12 题短版（HSPS-12）**，逐题严格取自 Aron 1997 原版 27 题的子集（对应原版第 2/7/8/10/14/16/18/21/22/23/25/26 题）。此 12 题子版被 Pluess & Boniwell (2015) 等使用（α≈.85）。
- **中文**：**没有权威的 27 题官方中文译本**（现有中文效度版或基于 Walda 38 题、或删题为 23 题，均非官方 27 题中文版）。故中文题目**由本项目译自 Aron 1997 英文原文**，代码中每题保留 `en` 英文原文，结果页脚注注明"中文译自 Aron & Aron 1997，仅供自我探索"。
- **计分**：7 点李克特（1=完全不符合 … 7=完全符合），无反向题，累加。12 题总分范围 **12–84**。
- **分级**：官方判定基于"是/否作答 ≥14/27 题为高敏感"，作者明确告诫"非诊断"。**"打分≥5 计 14 题"是民间改写、无权威出处，不采用。** 本页按连续分数做**分段描述**（低/中/高敏感倾向），不下二元"你是高敏感"标签，并注明非诊断。分段阈值来自把 12 题均分映射回官方 1997 的 7 点锚点（见下"计分实现"），页面标注为"参考分段"。

### 量表二：PSS 知觉压力量表

- **出处**：Cohen, S., Kamarck, T., & Mermelstein, R. (1983). *A global measure of perceived stress.* Journal of Health and Social Behavior, 24(4), 385–396；PSS-10 见 Cohen & Williamson (1988)。10 题英文原文已逐字核实（CMU Cohen 实验室官方 PDF）。
- **采用**：**PSS-10**，10 题英文原文对照，中文译自英文原文（`en` 字段保留原文）。
- **计分**：0–4（0=从不 … 4=总是），**反向计分题：第 4、5、7、8 题**（0↔4,1↔3,2↔2）。总分 **0–40**。
- **分级**：0–13 低 / 14–26 中 / 27–40 高。**作者从未发布官方切点**，此三档为广泛惯例（有人群常模背景），页面标注"参考区间，非诊断"。

## 约束（项目"宪法"，不可破）

- 纯 HTML+CSS+vanilla JS，无框架、无构建，localhost 直接跑。
- 注册为 `window.Pages.tests = { render(el) }`（同 chat.js/portrait.js/training.js）。
- 数据只经 `Store`（新增自建 key，见下）；AI 只调 `AI.chat`；颜色只用 `tokens.css` 变量。
- **只新增/编辑 `pages/tests.js`**，不动 `lib/`、不动其他页面、不改 index.html（它已 `<script src="pages/tests.js">`）。
- 无 API Key / AI 报错时用本地兜底解读，保证 demo 全程可跑（同 portrait.js 的 fallbackPoem 模式）。

## 文件改动

- **新增**：`huanbaoni/webapp/pages/tests.js`（样式内联 `injectStyle()`，同 portrait.js，避免改 index.html 多引 css）。
- 其余文件：**零改动**。

## 页面结构（单文件状态机，学 portrait.js / training.js）

```
render(el)
 ├─ view: 'home'      量表列表：两张卡（高敏感自测 / 压力自测）+ 上次得分 + 「测试记录」入口
 ├─ view: 'quiz'      逐题作答（进度条 + 李克特选项）
 ├─ view: 'result'    结果页：分数环 + 分段解释 + 小知解读 + 存档 + 免责声明
 └─ view: 'records'   历史存档列表 + 详情/删除
```

内部一个 `state = { view, scaleId, answers[], idx }` + `paint()` 重渲染当前 view，事件委托绑定。

### 量表数据模型（内置常量，每套带出处）

```js
const SCALES = [{
  id:'hsps', title:'高敏感自测', subtitle:'HSPS-12 · 了解你的感官敏感度',
  source:'Aron & Aron (1997), JPSP 73(2)',
  scaleType:'likert7',      // 1..7
  anchors:['完全不符合','','','中等','','','完全符合'],
  reverse:[],               // 无反向题
  items:[{ zh:'…', en:'Do you seem to be aware of subtleties in your environment?' }, ...12],
  bands:[...],              // 分段解释（见计分实现）
}, {
  id:'pss', title:'压力自测', subtitle:'PSS-10 · 近一个月的知觉压力',
  source:'Cohen et al. (1983); Cohen & Williamson (1988)',
  scaleType:'likert5',      // 0..4
  anchors:['从不','几乎没有','有时','经常','总是'],
  reverse:[3,4,6,7],        // 0-based：对应第4/5/7/8题
  items:[{ zh:'…', en:'In the last month, how often have you felt nervous and "stressed"?' }, ...10],
  bands:[{max:13,...},{max:26,...},{max:40,...}],
}];
```

### 计分实现

- **HSPS-12**：raw = Σ(1..7)，范围 12–84。分段用**均分**（raw/12，回到 1–7 锚点）：均分 <3.5 低敏感倾向 / 3.5–5.0 中等 / >5.0 高敏感倾向。（阈值来自 7 点量表中点附近的常识分段，页面标注"参考分段，非诊断"。）
- **PSS-10**：先对 `reverse` 题做 `4 - v`，再 Σ(0..4)，范围 0–40。分段 0–13 / 14–26 / 27–40。
- 每套 `bands` 存 `{label, desc}`，`desc` 是温柔、不下诊断的本地文案（也作 AI 不可用时的兜底解读主体）。

### 结果页

- **分数环**：SVG 圆环按 `score/maxScore` 填充，用 `--accent` / 压力三色（`--calm/--mid/--high`）表达分段，中心显示分数。
- **分段解释**：`band.label` + `band.desc`（本地，恒有）。
- **小知 AI 解读**：`AI.chat`，system 用 `AI.persona`（小知人设），user 传"量表名 + 分数 + 分段 + 各题作答摘要"，要求温柔、共鸣、不下诊断、给 1 个可操作的小邀请。失败/无 Key → 用本地兜底（band.desc + 一句通用陪伴语），toast「当前为离线示例」，绝不白屏。
- **免责声明**（恒显）：「本自测源自公开学术量表（{source}），仅供自我探索，不构成心理或医学诊断。」
- **戒指呼应（可选亮点）**：进入结果页若戒指已连，触发一次 `ring.vibrate('anchor')`（吸4·呼6）作"温柔收束"。无戒指静默跳过。
- 操作：存档（写 `hbn.tests`）、重测、返回。

### 存档 & 回看

- 完成即写一条记录到 `hbn.tests`。records 页倒序列出：量表名 + 日期 + 分数 + 分段，可查看详情（含当时解读）与删除。

## 数据（决策：自建 `hbn.tests`，不改 store.js 冻结接口）

沿用同类模块 F（training）的先例——[training spec](2026-07-31-training-page-design.md) 就是自建 `hbn.training`、页面内封装读写、不污染契约。本页同法：

```js
hbn.tests  // 测试存档
[{ id, ts, scaleId:'hsps'|'pss', title,
   score, maxScore, bandLabel, bandDesc,
   answers:number[],            // 原始作答（未反向），供回看
   interpretation }]            // 当时的解读（AI 或兜底）
```

读写封装在 tests.js 内（`loadRecords / addRecord / delRecord`，走 `localStorage` key `hbn.tests`），不动 `Store` 契约签名。

## 错误处理

- `AI.chat` 抛错（无 Key / 网络 / 超时）→ 落本地兜底解读，toast 提示，绝不白屏。
- 计分/存储异常 try/catch，降级为默认值。
- 整页 render 出错由 index.html 的 route try/catch 兜住，不影响其他 tab。
- localStorage 写失败（隐私模式）→ 存档静默失败 + toast，不阻断当次查看。

## 验收

1. 打开 index.html → 点「探索」→ 出两张量表卡（非占位）。
2. 高敏感自测：逐题作答（12 题，7 点）→ 结果页出分数环 + 分段 + 解读；分数计算正确。
3. 压力自测：逐题作答（10 题，5 点）→ 结果正确，**反向题（4/5/7/8）计分正确**（可用全选"从不"验证：反向题应得 4 分，总分=16）。
4. **不填 Key 全程可跑**（本地兜底解读）；填 Key 出小知个性化解读。
5. 结果可存档；records 页能查看历史、删除；退出重进仍在。
6. 每套结果页都显示**出处引用 + 非诊断免责声明**。
7. 控制台无红色报错；其他 5 个 tab 功能不受影响。
8. `git status` 仅新增 `pages/tests.js`（+ 本 spec）。

## 追加：HBTI 环抱型人格测试（原创四维·置顶）

> 2026-07-31 追加。用户希望有一款「环抱你自己的、类 MBTI 风格但完全原创」的人格测试作为探索页招牌，置顶展示。**HBTI = Huanbao Type Indicator（环抱型人格测试）**，中文主打、英文全称作副标题低调呈现。

### 与 MBTI 的根本区别（定位）

MBTI 测「你是怎样的人」（认知/性格类型）。**HBTI 测「你如何与世界、情绪、关系、自己相处，以及如何被疗愈」**——契合知愈"心灵感知与疗愈"定位，而非性格分类。四维**刻意跳出** MBTI 的 E/I·S/N·T/F·J/P，各自锚定一个独立的、已发表的心理学构念：

| 维度 | 两极（皆中性无褒贬） | 构念 & 出处（已 subagent 逐一核证原始来源） |
|---|---|---|
| **感知** 你如何接收世界 | 敏（细腻的感知）←→ 从（从容的感知） | 感觉加工敏感性 SPS：Aron & Aron (1997), *JPSP* 73(2)（子维 EOE/LST/AES 见 Smolewska et al., 2006） |
| **感受** 情绪如何流动 | 蕴（内蕴的感受）←→ 露（流露的感受） | 情绪表达/调节：Gross & John (2003), *JPSP* 85；参 Trapnell & Campbell (1999) RRQ |
| **联结** 从哪获得安全感 | 足（自足的联结）←→ 偎（依偎的联结） | 成人依恋：Brennan, Clark & Shaver (1998) ECR；Fraley et al. (2000) ECR-R |
| **复原** 受伤后怎么回来 | 柔（温柔的复原）←→ 坚（坚定的复原） | 自我关怀：Neff (2003), *Self and Identity* 2(3)；「坚」以行动/目标焦点(Higgins,1997)锚定 |

### 非病理化 / 诚实性红线（依核证报告，写进代码与免责声明）

核证报告标出三处"某一极关联更差心理结果"的陷阱，均已规避：

1. **感受**：ERQ 里"表达抑制"是**不良极**。故「蕴」**不锚定"压抑/憋着"**，而框为"先在心里消化、想明白再表达"（reflection 味），题目措辞刻意中性。
2. **联结**：依恋是**焦虑/回避两个正交维度**，非单轴。故本维明确是**原创"安全感来源"改写、受依恋启发**，**不是依恋诊断**；「自足」≠回避，「依偎」≠焦虑黏人。
3. **复原**：自我关怀的科学对立面是**自我批评**（不良极），**不是"上进/坚定"**。故「坚」**不锚定"低自我关怀/自我苛责"**，而锚定**行动/目标导向（促进焦点）**，使两极皆健康。

**免责声明恒显**（`HBTI_META.note` + `tmNote`）：本体验是原创自我探索、**非心理测评/诊断/临床评估**；四维受已发表研究启发但**题目原创、未经科学效度验证**；"类型"仅为便于理解的**比喻**、非科学分类；各维是**连续光谱、无好坏正常异常之分**；情绪困扰请求助专业。并声明**与 MBTI®、Myers-Briggs® 及基金会无任何关联**（HBTI 与 MBTI 结构相似且同品类，故显式切割）。

### 实现（全部在 `pages/tests.js`，零改其他文件）

- `HBTI_DIMS`（4 维，每维 neg/pos 极字 + 中文标签）、`HBTI_QUESTIONS`（16 题，5 点李克特，每题 `dim`+`dir`，原创措辞）、`HBTI_TYPES`（16 型：原型名+意象+描述+"被环抱的方式"，皆无褒贬）、`HBTI_META`。
- `scoreHBTI`：每维 raw = Σ(答案−3)·dir → 归一 [−1,1] → 符号定极、`50+|norm|·50` 映射为**主导极强度条 [50,100]%**（连续强度条，非硬二分，回应类型学最大争议）。
- 结果页：意象图（`hbtiImageSVG` 原创 SVG 兜底：敏→冷/从→暖，露→星点波纹/蕴→同心圆，种子取自类型码，确定性无随机；`enhanceHBTIPortrait` 有 Key 时用 `AI.image` 增强，抽象无人脸无文字莫兰迪风，静默兜底）+ 4 条强度条 + 描述 + 被环抱方式 + 小知解读 + 免责声明。
- 存档记录以 `kind:'hbti'` 标记（区别 `kind:'scale'`），records/详情页按 `kind` 分支；旧 HSPS/PSS（`kind:'scale'`）不受影响、不串档。
- 首页置顶 `#tsHero` 招牌卡（渐变、比量表卡更突出），点击进入 HBTI。

### 追加：代表物（灵性小生灵）+ 别称 + 油画宇宙

> 2026-07-31 再追加。用户反馈：①八个极字（敏/从·蕴/露·足/偎·柔/坚）拗口、传播度低；②希望每型像 MBTI 的小蝴蝶/小画家那样，有**自己的画像 + 代表物**，别称由代表物衍生，结果页同时呈现；③画风用小知油画风，打造「环抱人格宇宙」。用户经 AskUserQuestion 确认：**保留 HBTI 名**、品类=**环抱型人格测试**、代表物=**灵性小生灵（动物）**、极字=**退回后台只计分**（不再作为用户身份展示）。

- **极字退回后台**：4 字内部码（如 `敏蕴足柔`）仅用于 `scoreHBTI` 计分与 `HBTI_TYPES` 索引，**不再在任何用户界面**（结果页/记录页/详情页/招牌卡）出现。UI 身份 = 别称 + 原型名 + 代表物 emoji。
- **每型三字段**：`HBTI_TYPES` 每型新增 `nickname`（别称，源自代表物，如"林间小鹿""花间蝴蝶"）、`animal`（灵性小生灵）、`emoji`（该动物 emoji，作无 Key 兜底徽记）。16 型动物各异、皆温暖被珍视、无褒贬。
- `hbtiImageSVG(code, type)`：改为接收 type 对象，**居中渲染代表物 emoji**于原创油画感圆盘（敏→冷/从→暖主色、露→星点波纹/蕴→同心圆，种子取自类型码，确定性无随机，全部取 tokens.css 变量）——**无 Key 也不白板**。
- `enhanceHBTIPortrait`：有 Key 时 prompt 改为「单只 `${animal}` 的温柔油画、该原型的灵性代表物，意境=`${img}`，厚涂笔触、莫兰迪柔色、梦幻暖光、居中、无人脸无文字」，成功则替换 SVG（带 recId+mode+view 守卫防串档），失败静默回退 SVG。
- **持久化**：`finishHBTI` 记录新增 `nickname/animal/emoji`；记录页列表标题改为「emoji + 别称」（副行=原型名+日期），**不再显示拗口极字码**；详情页同样以别称为主、原型名为辅、居中代表物徽记。
- CSS：`.hb-nick`（别称，唯一标题，22px 粗）；移除死规则 `.hb-code`、`.hb-name`。
- 别称与原型名去重：原「别称 + 原型名 + 一句意象」三行里，原型名（如"巷口的暖灯"）与别称（"巷口松鼠"）前缀重复、语义又与意象行重叠，故**删原型名行**，只留「别称 + 一句意象」（结果页）/「别称 + 日期」（详情页）。原型名仍存于数据供 AI 解读与检索。

### 追加：双极强度条（找回四维极字批注）

> 2026-07-31 再追加。用户反馈：单向进度条只显示一个主导极标签（如"从容的感知 50%"），**看不出四维对应关系、也丢了最初的四维极字设定（敏蕴足柔）**。改为双极条：一眼看出"更靠近哪一端"，并把极字找回作维度批注（不复活孤立身份码）。

- `renderHBTIBars(bars)` 共享帮手（结果页 + 详情页复用，消除原重复渲染）：每维一行，**两极分列左右**——左端「极字（粗）+ 负极中文」（如 **柔** 温柔的复原），右端「正极中文 + 极字（粗）」（如 坚定的复原 **坚**）。
- 填充从**中线**出发偏向主导极：`lean = pct − 50`（0..50），主导右极 → `left:50%;width:lean%`（向右长）；主导左极 → `right:50%;width:lean%`（向左长）。主导极侧文字加深（`.hb-pole.on`）、极字用 `--accent-deep`，百分比贴在主导侧。
- 中线刻度 `.hb-bar-mid`，左右填充分别用正/反向 `--accent→--accent-deep` 渐变；均取 tokens.css 变量。375px 实机宽度下四维极字（敏蕴足柔/从露偎坚）与中文标签皆完整不裁切（headless Chrome 截图核过）。
- 极字定位：极字**仅作维度两极批注**回归界面，仍**不拼成孤立的 4 字身份码**（用户身份仍是别称+代表物）。

### 验收（HBTI 部分）

1. 探索页顶部出现「HBTI 环抱型人格测试」招牌卡；点击 → 16 题（5 点强度条李克特）。
2. 结果页出：**代表物徽记（居中）+ 别称（唯一标题）+ 一句意象** + **4 条双极强度条**（感知/感受/联结/复原，两极极字+中文分列左右，填充从中线偏向主导极 50–100%）+ 描述 + 被环抱方式 + 小知解读 + 免责声明；极字**仅作两极批注**、不拼成孤立身份码。
3. 四维**不是** MBTI 的 E/I·S/N·T/F·J/P；每维可溯到独立论文出处；每一极读起来**无褒贬**。
4. 无 Key 全程可跑（SVG 意象 + 本地兜底解读）；有 Key 出 AI 意象图与个性化解读。
5. 存档后 records 页 HBTI 与旧量表记录**并存不串**；`node --check` 通过；仅改 `pages/tests.js`（+本 spec）。

> 验证：`node --check pages/tests.js` 通过；DOM 沙盒断言全过（旧量表 + HBTI，含代表物别称/emoji 持久化、结果页展别称+徽记、记录页展别称且**不显极字码**、旧 HSPS/PSS 不串档），引擎另测：16 型全覆盖、名称唯一、极值 100%/均匀 50% 差异化正确。

## 明确不做（YAGNI）

- 不做性格（MBTI/大五）与情绪粒度测试的**科学量表版**（分工表列了"性格/情绪"；HBTI 以**原创、明确非验证**的自省体验形式满足"性格探索"需求，不冒充科学量表）。
- 不做云端同步、账号、跨设备。
- 不改 lib/ 任何契约接口，不引第三方库。
- 不使用无权威出处的"民间阈值"（如"打分≥5 计 14 题"）。
- HBTI 不冒充科学测量、不下诊断、不将任一极表述为"更好/异常"。

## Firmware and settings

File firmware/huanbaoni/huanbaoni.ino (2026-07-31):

/**********************************************************************
 * 环抱你 · 情绪戒指固件  huanbaoni.ino
 * 主控: ESP32-S3   传感: MAX30102(心率/HRV) + GSR + MPU6050   执行: 震动马达
 *
 * 功能:
 *   1) MAX30102 读脉搏 → 算心率 BPM 与 RR 间隔 → 算 HRV(RMSSD)
 *   2) GSR 皮肤电导 (GPIO10 ADC) → 上报唤醒水平
 *   3) MPU6050 六轴 → 算运动量 motion (给 H5 做运动伪迹闸门 + 坐立不安信号)
 *   4) MPU6050 检测"双击戒指"手势 → 上报 GESTURE=DBLTAP (H5 敲一下开始说话)
 *   5) 通过 BLE Notify 把 HR / HRV / GSR / MOTION / GESTURE 实时发给 H5 网页
 *   6) H5 发来 "VIBRATE:INTERCEPT/ANCHOR/RETREAT" → 三档干预触觉 (PWM 非阻塞)
 *        INTERCEPT 轻促短震 | ANCHOR 共振呼吸吸4呼6渐强渐弱x3 | RETREAT 两下长震
 *
 * ── 需要在 Arduino IDE 安装的库 (库管理器搜索安装) ──
 *   · SparkFun MAX3010x Pulse and Proximity Sensor Library
 *   (BLE 用 ESP32 板级自带的 BLEDevice；MPU6050 直接读寄存器免装库)
 *
 * ── 开发板设置 ──
 *   开发板: "ESP32S3 Dev Module"    上传卡在 Connecting… 时按住 BOOT 键
 *
 * ── 整机接线图 (针脚号按需改, 改下面的 #define 即可) ──
 *   MAX30102     ESP32-S3        MPU6050(GY-521)  ESP32-S3
 *     VIN  ->    3V3               VCC  ->  3V3
 *     GND  ->    GND               GND  ->  GND
 *     SDA  ->    GPIO8 (I2C)       SDA  ->  GPIO8 (并联)
 *     SCL  ->    GPIO9 (I2C)       SCL  ->  GPIO9 (并联)
 *                                  AD0  ->  GND
 *   震动马达(带驱动) ESP32-S3       GSR Sensor      ESP32-S3
 *     VCC  ->    3V3               VCC  ->  3V3
 *     GND  ->    GND               GND  ->  GND
 *     IN   ->    GPIO5             OUT  ->  GPIO10 (ADC1)
 *   (3V3 只有两个针脚 → 用面包板 +/− 电源轨给各模块分电)
 **********************************************************************/

#include <Wire.h>
#include "MAX30105.h"        // SparkFun 库(兼容 MAX30102)
#include "heartRate.h"       // SparkFun 的心跳检测算法
#include <BLEDevice.h>
#include <BLEServer.h>
#include <BLEUtils.h>
#include <BLE2902.h>
#include <math.h>

// ---------- 引脚 (按你的实际接线改) ----------
#define PIN_SDA    8         // I2C 数据 (心率 MAX30102 + 六轴 MPU6050 共用)
#define PIN_SCL    9         // I2C 时钟
#define PIN_MOTOR  5         // 震动马达
#define PIN_GSR    10        // 皮肤电 GSR 模拟输出 (必须 ADC1: GPIO1~10)

#define MPU_ADDR   0x68      // MPU6050 (GY-521) I2C 地址

// ---------- BLE 契约 UUID (必须与 H5 完全一致, 见 docs/接口契约.md) ----------
#define SERVICE_UUID  "19b10000-e8f2-537e-4f6c-d104768a1214"
#define HR_UUID       "19b10003-e8f2-537e-4f6c-d104768a1214"
#define HRV_UUID      "19b10005-e8f2-537e-4f6c-d104768a1214"
#define GSR_UUID      "19b10006-e8f2-537e-4f6c-d104768a1214"
#define MOTION_UUID   "19b10007-e8f2-537e-4f6c-d104768a1214"   // 运动量上行(六轴)
#define CMD_UUID      "19b10008-e8f2-537e-4f6c-d104768a1214"
#define GESTURE_UUID  "19b10009-e8f2-537e-4f6c-d104768a1214"   // 手势上行(敲击唤醒)
#define DEVICE_NAME   "HuanbaoNi"

MAX30105 sensor;
bool mpuOk = false;         // MPU6050 是否在线 (缺了不影响主流程)

// ---------- 心率 / HRV 计算 ----------
const byte RATE_SIZE = 8;
byte rates[RATE_SIZE];
byte rateSpot = 0;
long lastBeat = 0;
float beatsPerMinute = 0;
int beatAvg = 0;

// RR 间隔缓冲, 用于 RMSSD
const int RR_SIZE = 12;
long rrIntervals[RR_SIZE];
int rrCount = 0;
float hrvRMSSD = 0;

// ---------- MPU6050 六轴: 运动量 + 敲击手势 ----------
float motionSmooth = 0;          // 平滑后的运动量(°/s 级)
float accBaseline  = 1.0;        // 加速度幅度基线(g), 慢跟随重力
// 双击检测状态机
unsigned long lastTapMs = 0;     // 上一次单击时刻
unsigned long tapRefractoryUntil = 0;  // 单击不应期, 防抖
bool  pendingGesture = false;    // 有待上报的双击

// ---------- BLE ----------
BLEServer* pServer = nullptr;
BLECharacteristic *chHR, *chHRV, *chGSR, *chMotion, *chGesture;
bool deviceConnected = false;

// ========== 三档干预触觉引擎 (非阻塞, PWM 步进) ==========
// 见 docs/接口契约.md §1:
//   HAP_INTERCEPT 档三·早期拦截: 单次轻促短震 ~150ms (低强度)
//   HAP_ANCHOR    档二·实时锚点: 共振呼吸 吸4·呼6 (无屏息), 吸气渐强/呼气渐弱, 循环 3 轮 (中强度)
//   HAP_RETREAT   档一·撤退许可: 两下长震 长-停-长, each ~600ms (最强度)
enum { HAP_NONE = 0, HAP_INTERCEPT, HAP_ANCHOR, HAP_RETREAT };

// LEDC (PWM) 配置: 用占空比模拟震动强度渐变
#define MOTOR_PWM_CH    0
#define MOTOR_PWM_FREQ  200      // Hz, 马达可跟随的低频
#define MOTOR_PWM_RES   8        // 8bit → 占空 0..255
#define MOTOR_GAIN      2.0f     // 整体震动强度倍率 (翻倍; 超过 255 自动封顶)

int   hapMode  = HAP_NONE;       // 当前正在播放的档位
int   hapStep  = 0;              // 当前处于序列的第几步
int   hapCycle = 0;              // anchor: 已完成的呼吸轮数
unsigned long hapStepUntil = 0;  // 当前步的结束时刻

// 呼吸参数 (共振呼吸 吸4·呼6, 单位 ms)
const int BR_IN_MS   = 4000;     // 吸气 4s (渐强)
const int BR_OUT_MS  = 6000;     // 呼气 6s (渐弱)
const int BR_CYCLES  = 3;        // 循环 3 轮
const int BR_MAX_DUTY = 200;     // 呼吸档峰值强度 (中强度)

void motorDuty(int duty) {       // duty 0..255 (输入按 MOTOR_GAIN 放大后封顶)
  duty = (int)(duty * MOTOR_GAIN);
  if (duty < 0) duty = 0; if (duty > 255) duty = 255;
  ledcWrite(PIN_MOTOR, duty);    // core v3.x: 按引脚写占空
}

// 启动某一档触觉 (会打断上一次未播完的序列)
void startHaptic(int mode) {
  hapMode = mode; hapStep = 0; hapCycle = 0;
  hapStepUntil = 0;             // 立即在 updateHaptic 里进入第 0 步
  Serial.print("[HAPTIC] start mode="); Serial.println(mode);
}

// 每次 loop 调一次: 按当前档位推进非阻塞序列
void updateHaptic() {
  if (hapMode == HAP_NONE) return;
  unsigned long now = millis();

  // 呼吸档: 在一步内做连续渐变, 每 tick 都要刷新占空, 不能只在切步时刷
  if (hapMode == HAP_ANCHOR) {
    if (hapStep == 0) {          // 吸气渐强
      if (hapStepUntil == 0) hapStepUntil = now + BR_IN_MS;
      long remain = (long)hapStepUntil - (long)now;
      if (remain <= 0) { hapStep = 1; hapStepUntil = now + BR_OUT_MS; }
      else {
        float p = 1.0f - (float)remain / BR_IN_MS;   // 0→1
        motorDuty((int)(BR_MAX_DUTY * p));
      }
      return;
    } else {                      // 呼气渐弱
      long remain = (long)hapStepUntil - (long)now;
      if (remain <= 0) {
        hapCycle++;
        if (hapCycle >= BR_CYCLES) { motorDuty(0); hapMode = HAP_NONE; Serial.println("[HAPTIC] anchor done"); }
        else { hapStep = 0; hapStepUntil = now + BR_IN_MS; }
      } else {
        float p = (float)remain / BR_OUT_MS;         // 1→0
        motorDuty((int)(BR_MAX_DUTY * p));
      }
      return;
    }
  }

  // 拦截档 / 撤退档: 离散的开-关序列, 只在切步时改占空
  if (now < hapStepUntil) return;  // 当前步还没走完
  switch (hapMode) {
    case HAP_INTERCEPT:            // 单次轻促短震
      if (hapStep == 0) { motorDuty(120); hapStepUntil = now + 150; hapStep = 1; }
      else              { motorDuty(0);   hapMode = HAP_NONE; }
      break;
    case HAP_RETREAT:             // 长-停-长, 最强度
      switch (hapStep) {
        case 0: motorDuty(255); hapStepUntil = now + 600; hapStep = 1; break; // 长震1
        case 1: motorDuty(0);   hapStepUntil = now + 300; hapStep = 2; break; // 停
        case 2: motorDuty(255); hapStepUntil = now + 600; hapStep = 3; break; // 长震2
        default: motorDuty(0);  hapMode = HAP_NONE; break;
      }
      break;
    default: motorDuty(0); hapMode = HAP_NONE; break;
  }
}

// 上报节流
unsigned long lastNotify = 0;

// ================= BLE 回调 =================
class ServerCB : public BLEServerCallbacks {
  void onConnect(BLEServer* s) override { deviceConnected = true; Serial.println("[BLE] 已连接"); }
  void onDisconnect(BLEServer* s) override {
    deviceConnected = false;
    Serial.println("[BLE] 断开, 重新广播");
    BLEDevice::startAdvertising();
  }
};

// 前置声明：触发三档触觉
void startHaptic(int mode);

// 收到 H5 指令 (下行)
class CmdCB : public BLECharacteristicCallbacks {
  void onWrite(BLECharacteristic* c) override {
    String v = c->getValue().c_str();
    Serial.print("[CMD] 收到: "); Serial.println(v);
    if (v.startsWith("VIBRATE")) {
      // 三档干预触觉 (见 docs/接口契约.md §1)
      if      (v.indexOf("INTERCEPT") >= 0) startHaptic(HAP_INTERCEPT);
      else if (v.indexOf("RETREAT")   >= 0) startHaptic(HAP_RETREAT);
      else                                  startHaptic(HAP_ANCHOR); // ANCHOR / 无参兼容
    }
  }
};

void computeRMSSD() {
  if (rrCount < 3) { hrvRMSSD = 0; return; }
  double sumSq = 0; int n = 0;
  for (int i = 1; i < rrCount; i++) {
    long d = rrIntervals[i] - rrIntervals[i - 1];
    sumSq += (double)d * d; n++;
  }
  hrvRMSSD = (n > 0) ? sqrt(sumSq / n) : 0;
}

// ========== MPU6050 (六轴): 运动量 + 敲击手势 ==========
bool mpuWrite(uint8_t reg, uint8_t val) {
  Wire.beginTransmission(MPU_ADDR);
  Wire.write(reg); Wire.write(val);
  return Wire.endTransmission() == 0;
}

// 探测并唤醒 MPU6050; 缺失也不影响主流程
void mpuInit() {
  Wire.beginTransmission(MPU_ADDR);
  if (Wire.endTransmission() != 0) { mpuOk = false; Serial.println("[warn] 未检测到 MPU6050, 跳过六轴/手势"); return; }
  mpuWrite(0x6B, 0x00);   // 退出睡眠
  delay(50);
  mpuOk = true;
  Serial.println("[OK] MPU6050 就绪 (运动量 + 敲击唤醒)");
}

// 每次 loop 调: 读六轴 → 更新 motionSmooth + 检测双击 → pendingGesture
void mpuUpdate() {
  if (!mpuOk) return;
  Wire.beginTransmission(MPU_ADDR);
  Wire.write(0x3B);
  if (Wire.endTransmission(false) != 0) return;
  Wire.requestFrom(MPU_ADDR, 14, true);
  if (Wire.available() < 14) return;
  int16_t ax = (Wire.read() << 8) | Wire.read();
  int16_t ay = (Wire.read() << 8) | Wire.read();
  int16_t az = (Wire.read() << 8) | Wire.read();
  Wire.read(); Wire.read();                 // 温度跳过
  int16_t gx = (Wire.read() << 8) | Wire.read();
  int16_t gy = (Wire.read() << 8) | Wire.read();
  int16_t gz = (Wire.read() << 8) | Wire.read();

  // 运动量: 陀螺仪角速度幅度 (°/s), 静止≈0
  float gmag = (fabs((float)gx) + fabs((float)gy) + fabs((float)gz)) / 131.0f;
  motionSmooth = motionSmooth * 0.8f + gmag * 0.2f;

  // 敲击检测: 加速度幅度相对基线的突增(jerk)
  float amag = sqrtf((float)ax*ax + (float)ay*ay + (float)az*az) / 16384.0f; // g
  accBaseline = accBaseline * 0.95f + amag * 0.05f;   // 慢跟随(重力+姿态)
  float jerk = fabs(amag - accBaseline);

  unsigned long now = millis();
  const float TAP_JERK = 0.9f;        // 敲击阈值(g), 需明显磕一下
  const unsigned long REFRACTORY = 60;    // 单次敲击不应期(ms), 防一击多计
  const unsigned long DBL_MIN = 80, DBL_MAX = 600; // 双击间隔窗口(ms)

  if (jerk > TAP_JERK && now > tapRefractoryUntil) {
    tapRefractoryUntil = now + REFRACTORY;
    unsigned long gap = now - lastTapMs;
    if (gap > DBL_MIN && gap < DBL_MAX) {
      pendingGesture = true;          // 命中双击
      lastTapMs = 0;                  // 复位, 避免三击连锁
      Serial.println("[GESTURE] 双击 DBLTAP");
    } else {
      lastTapMs = now;                // 记为第一击
    }
  }
}

void setup() {
  Serial.begin(115200);
  delay(1500);          // 等 ESP32-S3 的 USB-CDC 枚举完, 否则开机自检的串口打印会被吞掉
  Serial.println("\n=== 环抱你 戒指启动 ===");

  // 马达用 LEDC(PWM) 驱动, 支持强度渐变(呼吸档渐强渐弱)
  // ESP32 Arduino core v3.x API: ledcAttach(pin, freq, resolution)
  ledcAttach(PIN_MOTOR, MOTOR_PWM_FREQ, MOTOR_PWM_RES);
  motorDuty(0);

  // 开机自检: 震两下, 独立于传感器/BLE 验证马达线是否通
  // (看不到震动 = GPIO5/GND/VCC 接线或驱动板问题, 与 BLE/手指无关)
  Serial.println("[自检] 马达震两下...");
  motorDuty(200); delay(250); motorDuty(0); delay(200);
  motorDuty(200); delay(250); motorDuty(0);

  // I2C + MAX30102
  Wire.begin(PIN_SDA, PIN_SCL);
  if (!sensor.begin(Wire, I2C_SPEED_FAST)) {
    Serial.println("[ERR] 找不到 MAX30102, 检查接线/供电(3.3V)!");
    while (1) { delay(1000); }
  }
  sensor.setup();                 // 默认配置
  sensor.setPulseAmplitudeRed(0x0A);
  sensor.setPulseAmplitudeGreen(0);
  Serial.println("[OK] MAX30102 就绪, 手指请轻贴传感器");

  // MPU6050 六轴 (运动量 + 敲击唤醒); 与 MAX30102 共用 I2C 总线
  mpuInit();

  // GSR 皮肤电 ADC
  analogReadResolution(12);
  analogSetPinAttenuation(PIN_GSR, ADC_11db);

  // BLE
  BLEDevice::init(DEVICE_NAME);
  pServer = BLEDevice::createServer();
  pServer->setCallbacks(new ServerCB());
  BLEService* svc = pServer->createService(SERVICE_UUID);

  chHR = svc->createCharacteristic(HR_UUID, BLECharacteristic::PROPERTY_NOTIFY);
  chHR->addDescriptor(new BLE2902());
  chHRV = svc->createCharacteristic(HRV_UUID, BLECharacteristic::PROPERTY_NOTIFY);
  chHRV->addDescriptor(new BLE2902());
  chGSR = svc->createCharacteristic(GSR_UUID, BLECharacteristic::PROPERTY_NOTIFY);
  chGSR->addDescriptor(new BLE2902());
  chMotion = svc->createCharacteristic(MOTION_UUID, BLECharacteristic::PROPERTY_NOTIFY);
  chMotion->addDescriptor(new BLE2902());
  chGesture = svc->createCharacteristic(GESTURE_UUID, BLECharacteristic::PROPERTY_NOTIFY);
  chGesture->addDescriptor(new BLE2902());

  BLECharacteristic* chCmd = svc->createCharacteristic(CMD_UUID, BLECharacteristic::PROPERTY_WRITE);
  chCmd->setCallbacks(new CmdCB());

  svc->start();
  BLEAdvertising* adv = BLEDevice::getAdvertising();
  adv->addServiceUUID(SERVICE_UUID);
  adv->setScanResponse(true);
  BLEDevice::startAdvertising();
  Serial.println("[OK] BLE 广播中, 设备名: " DEVICE_NAME);
}

void loop() {
  // 三档触觉引擎: 非阻塞推进当前震动序列
  updateHaptic();

  // 六轴: 更新运动量 + 检测双击 (高频, 每 loop 都读, 才抓得住敲击)
  mpuUpdate();

  // 双击手势即时上报 (不等 1s 节流, 保证"敲一下"低延迟)
  if (pendingGesture) {
    pendingGesture = false;
    if (deviceConnected) {
      const char* g = "DBLTAP";
      chGesture->setValue((uint8_t*)g, strlen(g));
      chGesture->notify();
    }
  }

  // 读一次 IR, 检测心跳
  long irValue = sensor.getIR();
  if (irValue > 50000) {                 // 有手指
    if (checkForBeat(irValue)) {
      long now = millis();
      long delta = now - lastBeat;
      lastBeat = now;
      beatsPerMinute = 60.0 / (delta / 1000.0);
      if (beatsPerMinute > 20 && beatsPerMinute < 255) {
        rates[rateSpot++] = (byte)beatsPerMinute;
        rateSpot %= RATE_SIZE;
        int sum = 0; for (byte i = 0; i < RATE_SIZE; i++) sum += rates[i];
        beatAvg = sum / RATE_SIZE;

        // 记 RR 间隔算 HRV
        if (rrCount < RR_SIZE) rrIntervals[rrCount++] = delta;
        else { for (int i = 1; i < RR_SIZE; i++) rrIntervals[i-1] = rrIntervals[i]; rrIntervals[RR_SIZE-1] = delta; }
        computeRMSSD();
      }
    }
  } else {
    beatAvg = 0;   // 没手指
  }

  // 每 1s 上报一次生理/运动信号
  if (millis() - lastNotify > 1000) {
    lastNotify = millis();

    int gsr = analogRead(PIN_GSR);
    Serial.printf("HR=%d  HRV=%.1fms  GSR=%d  MOTION=%.0f  IR=%ld\n",
                  beatAvg, hrvRMSSD, gsr, motionSmooth, irValue);

    if (deviceConnected) {
      // HR: int → 字符串上报 (H5 端按文本解析, 简单可靠)
      char bufHr[8];  snprintf(bufHr, sizeof(bufHr), "%d", beatAvg);
      chHR->setValue((uint8_t*)bufHr, strlen(bufHr));
      chHR->notify();

      char bufHrv[12]; snprintf(bufHrv, sizeof(bufHrv), "%.1f", hrvRMSSD);
      chHRV->setValue((uint8_t*)bufHrv, strlen(bufHrv));
      chHRV->notify();

      // GSR 皮肤电 (0-4095 原始值)
      char bufG[8]; snprintf(bufG, sizeof(bufG), "%d", gsr);
      chGSR->setValue((uint8_t*)bufG, strlen(bufG));
      chGSR->notify();

      // MOTION 运动量 (给 H5 做运动伪迹门控 + 坐立不安信号)
      if (mpuOk) {
        char bufM[8]; snprintf(bufM, sizeof(bufM), "%d", (int)motionSmooth);
        chMotion->setValue((uint8_t*)bufM, strlen(bufM));
        chMotion->notify();
      }
    }
  }
}

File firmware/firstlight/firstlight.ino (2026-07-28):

/**********************************************************************
 * 环抱你 · 第一束光  firstlight.ino
 * 用途: 你的第一次烧录, 验证"能烧录 + 串口能通"。
 * 这块板(ESP32-S3-N16R8)的用户灯是 GPIO48 上的 RGB 彩灯,
 * 所以用彩灯循环变色来确认烧录成功(普通 Blink 看不到)。
 *
 * 不用接任何线, 只要板子插着 USB 就行。
 *
 * Arduino IDE 设置(Tools 菜单):
 *   Board: "ESP32S3 Dev Module"
 *   Port : /dev/cu.usbmodem5CBC3861781
 *   USB CDC On Boot: "Enabled"   ← 必须开, 否则串口看不到字
 *   Flash Size: "16MB (128Mb)"
 *   PSRAM: "OPI PSRAM"
 * 上传卡在 Connecting… 就按住板上 BOOT 键不放, 等开始上传再松。
 **********************************************************************/

#define RGB_PIN 48   // 板载 RGB 灯在 GPIO48

void setup() {
  Serial.begin(115200);
  delay(300);
  Serial.println("\n=== 环抱你 firstlight 启动成功! ===");
}

void loop() {
  Serial.println("我还活着~ (串口正常)");

  rgbLedWrite(RGB_PIN, 30, 0, 0);   delay(400);  // 红
  rgbLedWrite(RGB_PIN, 0, 30, 0);   delay(400);  // 绿
  rgbLedWrite(RGB_PIN, 0, 0, 30);   delay(400);  // 蓝
  rgbLedWrite(RGB_PIN, 0, 0, 0);    delay(400);  // 灭
}

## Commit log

2026-07-27 [init] 并行开发启动包: 接口契约 + 分工清单 + mock.js + gitignore
2026-07-27 [契约层+固件] tokens/store/ai/index 完成; huanbaoni.ino 固件(HR/HRV/BLE/震动)
2026-07-28 [realtime+ble] 核心闭环打通: Web Bluetooth 连戒指→假心率仪表盘→压力→私密震动→时间线
2026-07-28 [portrait] 今日心灵画像页: 情绪数据→gpt-image-2莫兰迪画+AI解读
2026-07-29 [ai] 修复: gpt-5.6-sol 不支持自定义temperature, 默认不传→画像AI解读恢复
2026-07-29 [ai] base_url 自动补全 /v1, 容错用户少填
2026-07-29 [portrait] 解读改为分行短诗+楷体诗意排版
2026-07-29 [portrait] 分行按标点切短句, 更像诗
2026-07-29 [portrait] 16情绪补录: 戒指测波动+用户选情绪→融合色板+情绪关键词入生图prompt
    [electronics_tray_140x95.obj, electronics_tray_140x95.stl, feelingmosaic_ring_18.5mm.obj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]
2026-07-30 [firmware] 加 mictest: INMP441 I2S 麦克风响度测试
    [faceted_mosaic_core.obj, faceted_mosaic_core.stl, feelingmosaic_luxury_ring_18.5mm.obj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]
2026-07-30 四传感器整机集成: z-score融合算法+GSR/MPU上报+敲击唤醒语音+科学依据
2026-07-31 chore: 忽略 Python __pycache__/*.pyc
    cad/blender 脚本运行会产生缓存, 不入库。
2026-07-31 firmware: 目录化 huanbaoni.ino + 开机马达自检
    - 移到 firmware/huanbaoni/ 子目录, 符合 Arduino 项目结构。
    - setup 开机震两下自检马达线路, 独立于传感器/BLE。
    - USB-CDC 枚举延时 300→1500ms, 防自检串口打印被吞。
2026-07-31 cad: 加入 FeelingMosaic 戒指造型迭代 V3–V9
    Blender 参数化生成脚本 + 三尺寸 STL/OBJ 输出 + 预览图 + 设计说明:
    开口拥抱/极简/内向手掌/立掌/加长圆指/张开拇指 等姿态探索。
    [feelingmosaic_flush_hands_ring_18.5mm.obj, feelingmosaic_flush_hands_ring_18.5mm.stl, feelingmosaic_flush_hands_ring_19.5mm.obj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]
2026-07-31 hardware: 外壳装配修正 (圆形手臂凹座 + 双出线孔 + 传感器托盘)
    - 手臂安装改矩形脚为圆形凹座, 圆对圆自对位更贴合。
    - 侧墙抬高并开双圆孔, 分走 GSR 电极线与马达线, 避开面包板。
    - MAX30102 工字托盘中柱减半、MPU6050 横槽加长, 排针不再卡住。
    - 移除盖顶双手浅窝(改为轻搭盖顶), 补装配顺序: 先盖盖再粘臂。
    - 重新导出 STL/预览图, 加硬件规格文档与元件参考照片。
    [arms.stl, enclosure.scad, tray.stl]
2026-07-31 webapp: 加共享库层 (markdown/knowledge/imagestore) + trend 契约
    - markdown.js: 浏览器版轻量 Markdown→HTML, 供小知富文本回复。
    - knowledge.js: 心理/脑科学知识卡 + 关键词命中注入 system prompt,
    并在 ai.js 增「讲知识时」话术, 让小知讲原理又准又接地气。
    - imagestore.js: 画像图片存 IndexedDB, 避免 localStorage QuotaExceeded。
    - store.js: 新增 getTrend/addTrendSample 压力指数时间序列, 更新接口契约。
2026-07-31 webapp(portrait): 诚实的情绪可视化, 不美化负面情绪
    - emotions.js: 16 情绪加 valence 效价 + visual 画面词库。
    - ai.js portraitPrompt 重写: 负向情绪压暗去饱和调色板 + 明确
    禁止美化(no 阳光/彩虹/花草/治愈感), 用构图光线重量诚实承载。
    - portrait.js: 波动强度分级为 high/mid/low 动势, 传情绪对象与效价。
2026-07-31 webapp: 环抱页 24h 情绪趋势图 + 心迹(成长轨迹)页
    - realtime.js: 加 GSR/运动指标说明 + 24h 压力起伏折线图(读 trend)。
    - growth.js: 长期"被理解"可视化——温柔回访/画像画廊/情绪月历/
    情感粒度档案, 只读聚合; HSP 约束: 不做打卡施压/断签焦虑。
2026-07-31 webapp(tests): 探索页——HSPS-12 + PSS-10 学术量表自测
    题目逐字溯源已发表量表(Aron&Aron 1997 / Cohen 1983), 不编造;
    选题→计分→AI 解读→存档闭环, 无 Key 时本地兜底不白屏。
    数据走自建 hbn.tests, 不改 store.js 契约。
2026-07-31 webapp(training): 修习页——模拟对话训练 + 感官写作
    搬知愈小程序两个训练玩法为 vanilla-JS: AI 同演 NPC+小知教练逐轮
    点评打分; 选情绪场景→感官引导+词卡→拼成段落存档。
    无 Key 时全程 mock 兜底, 数据走自建 hbn.training。
2026-07-31 webapp: 整体外壳重设计 + 小知浮窗对话
    - index.html: 手机框投屏预览 + 5 tab 导航(环抱居中凸起 FAB) +
    小知改为主页浮窗唤起的底部 overlay(旧 #chat 链接重定向)。
    - tokens.css: 暖白光晕背景 + 标题宋体/正文黑体 + 柔光阴影/缓动。
    - huanbao-mark.svg: 银色金属标志改为暖色环抱心形。
    - chat.js: 自定义波形语音条替换原生 audio, 富文本渲染小知回复,
    无 Key 时命中知识卡兜底讲解。
2026-07-31 feat: 环抱你 H5 语音闭环 + 敲击直达 + 数字读法 + 硬件人形建模
    语音(tts.js 新增)
    - Qwen3-TTS aiden 男声，声线一致：整段回复合并为单段（_forOneShot 标点归一），杜绝分段导致的音色漂移
    - split_granularity 用 sentence（服务端不再支持 paragraph）
    - 数字规则：时间/电话/百分比/序号一律读中文，避免蹦英文数字
    - 语速 DEFAULT_RATE 1.25
    交互
    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
    [arms.stl, enclosure.scad, feet.stl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]
2026-07-31 fix(tts): 修复 DEFAULT_RATE 暂时性死区导致语音整体崩溃
    CFG.rate 在对象初始化时立即调用 _loadRate()，但 DEFAULT_RATE(const)
    定义在其后，触发 TDZ ReferenceError，导致 tts.js 加载失败、连带
    打断后续脚本（实时心率刷新等）。将 rate 相关定义上移到 CFG 之前。
    另附 firmware/i2c_scan：独立 I2C 扫描 + MAX30102 原始 IR 探测草稿，
    用于排查心率"时准时不准"（已确认为佩戴接触问题，硬件正常）。
    [i2c_scan.ino]
2026-07-31 fix(store): 写死默认 API 网关+key，线上零配置即可调通 AI/生图
    线上(GitHub Pages from main)之前 store.js 默认 apiBaseUrl/apiKey 为空，
    手机开线上页面 chat 与生图全部"AI 未配置"失败。补上写死默认值并对
    老缓存(存过空值)做兜底，手机连内网 WiFi 即可直接调通内网网关。
2026-07-31 ci: 落地 GitHub Pages 上线 workflow + 现场二维码工具
    之前上线方案只在从未推送的 feature/h5-publish 分支上，main 缺 pages.yml，
    导致 Actions 从未构建、线上一直 404。此提交把 workflow 合入 main：
    push 命中 webapp/** 即自动把 webapp/ 发布为站点根
    → https://lessie-wang.github.io/huanbaoni/
    - .github/workflows/pages.yml: 加 enablement:true 尝试自动开启 Pages
    - tools/make_qr.py + README: 现场保险(本机起服务 + 局域网二维码 fallback)
2026-07-31 docs: 加项目 README + 海报素材
    - README: 项目总览、目录结构、H5/固件/部署说明、线上地址
    - poster/: 环抱你宣传海报 (html + 渲染图 + 生成脚本)
2026-07-31 assets: 归拢「环抱你」全部提交物料(封面/海报/demo/二维码/易拉宝/logo/netlify包) + 海报/提测截图/代理脚本；忽略本地证书与切片错误转储
2026-07-31 docs(README): 页面表加「类型」列，明确 5 Tab + 小知悬浮窗，与「5 个 Tab」表述对齐
2026-08-01 docs(README): 体验链接改用 https://huanbaoni.netlify.app/（替换需内网登录的 cowork 链接）
2026-08-01 feat(chat): 小知对话轻量沉淀到心迹——离开页时摘一条情绪事件
    每次和小知聊完、离开小知页(hashchange 非 chat)时，把这次对话摘成一条
    心迹事件存进 Store，心迹页/日历/着色零改动即可显示：
    - 优先让小知读整段对话 → 选 16 词表之一的 mood + 一句 ≤20 字第一人称小结
    - AI 失败/断网兜底：关键词粗扫情绪 + 截取用户最后一句当 note，现场不丢
    - 存为 Store.addEvent({type:'chat', mood, note, source:'xiaozhi'})
    - 防重：一次对话只摘一次；纯看开场白不发言 → 不入库
    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
2026-08-01 content: 小知复盘话术改为「只呈现不对立」+ 海报文案戒指→伙伴
    - ai.js: 复盘 prompt 去掉「拿主观感受反驳身体信号」的对立说法，改为只客观呈现身体信号、把解释权交还用户
    - poster/ + submission_screenshots/: 文案与配图更新（戒指→伙伴 等）
2026-08-01 fix(chat): 摘要异步落库后，若停在心迹页则自动重渲染
    AI 摘要需 await 几秒才写库，用户往往已切到心迹页且渲染早于写库→看不到新记录。
    写库完成时若正停在 growth 页，主动重渲染一次使其立即可见。
2026-08-01 assets: 更新海报/提交截图导出 + 加封面 jpg
2026-08-04 chore: 更新 poster 与提交封面素材
